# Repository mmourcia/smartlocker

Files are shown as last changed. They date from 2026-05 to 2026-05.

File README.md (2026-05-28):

# Smart Locker - Casiers connectés pilotés par Home Assistant

Une personne dépose un colis dans un casier libre, l'affecte à un destinataire via une interface mobile, et ce destinataire reçoit une notification puis récupère son colis en tapant son code personnel devant le meuble. Pas de clé, pas de badge obligatoire, pas d'attente.

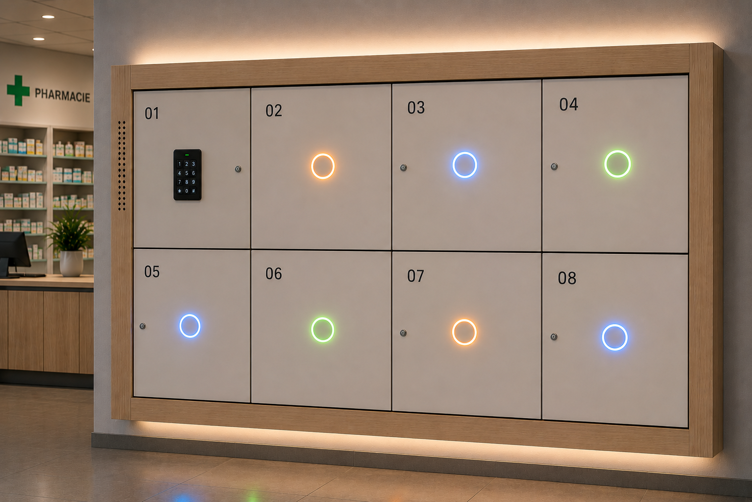
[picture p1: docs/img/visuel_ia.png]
Visuel IA


---

## Le principe

Le support est une étagère **IKEA Kallax 4x2** (8 casiers), chaque case étant équipée d'une porte, d'une serrure solénoïde et d'un anneau LED pour communiquer l'état au gestionnaire comme au destinataire.

Le cerveau du système est un **Raspberry Pi 4** sous Home Assistant OS. Deux cartes ESP32 lui sont connectées en WiFi : une carte 8 relais qui pilote les serrures et lit l'état des portes, et un digicode Wiegand 26 positionné devant le meuble.

Le système est conçu pour un usage intérieur en environnement de confiance. Pas de sécurité de niveau industriel : l'objectif est la praticité et la traçabilité légère.

---

## Ce que voit l'utilisateur

Un casier passe par quatre états, lisibles d'un coup d'oeil sur l'anneau LED :

| Couleur | État |
|---|---|
| 🟢 Vert fixe | Casier libre |
| 🔵 Bleu fixe | Occupé, destinataire notifié |
| 🟢 Vert clignotant (un seul, autres éteints) | Code correct, ce casier va s'ouvrir |
| 🟠 Orange clignotant | Porte ouverte depuis trop longtemps |
| 🔴 Rouge clignotant (tous, 3s) | Code incorrect |
| 🔴 Rouge fixe | Casier hors service |

---

## Documentation technique

Tout ce qu'il faut pour construire et configurer le système :

- [Serrure solénoïde](docs/hardware/serrure.md) - pilotage relais et retour via reed switch
- [Alimentation](docs/hardware/alimentation.md) - architecture 230V / 12V 20A
- [Contrôleur LED WLED Gledopto](docs/hardware/wled-gledopto.md) - 4 voies pour 8 casiers
- [Fraisage logements LED](docs/hardware/fraisage.md) - gabarit 3D et défonceuse
- [ESPHome - Carte relais](docs/esphome/carte-relais.md) - config complète LC-Relay-ESP32-8R-D5
- [ESPHome - Digicode Wiegand 26](docs/esphome/digicode-wiegand.md) - saisie code PIN
- [Home Assistant - Intégrations](docs/home-assistant/integrations.md) - entités, helpers, automatisations
- [Backend Python](docs/backend/README.md) - logique métier (à venir)

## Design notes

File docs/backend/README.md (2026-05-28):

# Backend Python - Logique métier

> **Statut : à venir.** Cette section sera complétée quand le backend sera développé.

## Motivation

Les automatisations Home Assistant YAML atteignent leurs limites pour :
- La vérification des codes PIN (logique conditionnelle complexe sur N casiers × M utilisateurs)
- La gestion des états métier avec transitions validées
- L'historisation des événements (qui a ouvert quoi, quand)
- Une future API REST pour piloter le système depuis une app mobile

## Architecture envisagée

```
Home Assistant
    │  webhooks / MQTT / WS
    ▼
Backend Python (FastAPI ou Flask)
    ├── Gestion des casiers (états, attribution, historique)
    ├── Gestion des utilisateurs (PIN hashé, préférences)
    ├── Vérification PIN (bcrypt)
    └── Notifications (email, push)
    │
    ▼
SQLite (ou PostgreSQL si volumétrie)
```

## Interactions avec Home Assistant

Le backend peut interagir avec HA de plusieurs façons :

| Mécanisme | Sens | Usage |
|---|---|---|
| Webhook HA | HA → Backend | Transmettre le code saisi par le digicode |
| REST API HA | Backend → HA | Déclencher ouverture (`button.press`), changer LED |
| MQTT | Bidirectionnel | Bus événements temps réel |
| Long-lived token HA | Auth | Token d'accès pour l'API HA |

## Structure de projet envisagée

```
backend/
├── app/
│   ├── main.py          # Point d'entrée FastAPI
│   ├── models.py        # Modèles SQLAlchemy (Casier, Utilisateur, Événement)
│   ├── api/
│   │   ├── lockers.py   # Endpoints casiers
│   │   └── users.py     # Endpoints utilisateurs
│   ├── services/
│   │   ├── pin.py       # Vérification PIN, hash bcrypt
│   │   ├── ha_client.py # Client API Home Assistant
│   │   └── notify.py    # Notifications email/push
│   └── config.py        # Variables d'environnement
├── tests/
├── requirements.txt
└── .env.example
```

## Sécurité

- Les PIN seront stockés hashés avec **bcrypt** (pas en clair comme dans les helpers HA V1)
- Le backend tourne en local sur le Raspberry Pi, pas exposé sur internet
- Authentification par token entre HA et le backend

## Déploiement sur le Raspberry Pi

Le backend tournera probablement comme un **add-on Home Assistant** ou un service systemd,
en parallèle de Home Assistant OS.

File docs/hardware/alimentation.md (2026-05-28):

# Alimentation

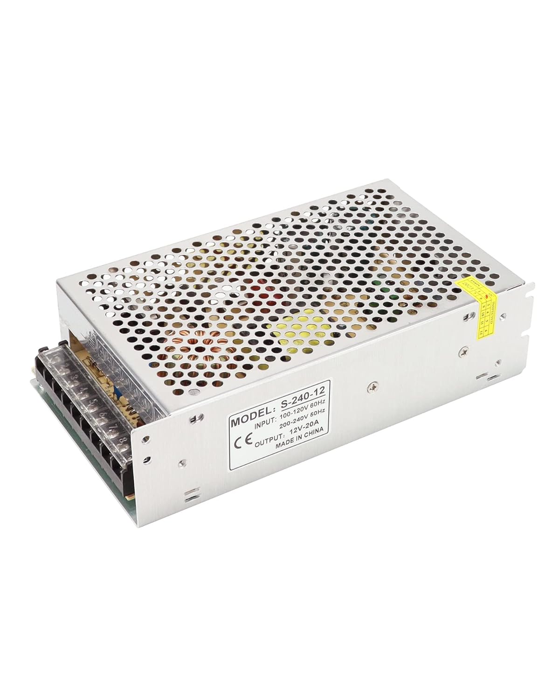
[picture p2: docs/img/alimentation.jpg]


## Architecture

| Source | Consommateur |
|---|---|
| Transformateur 12V / 20A | Carte ESP32, serrures x8, anneaux LED x8 |
| Alimentation USB-C officielle Raspberry Pi | Raspberry Pi 4 |

## Pourquoi 20A sur le 12V ?

| Consommateur | Courant estimé |
|---|---|
| Solénoïdes x8 (inrush simultané max) | 8 x 1 A = 8 A |
| Carte LC-Relay-ESP32-8R-D5 | ~0,5 A |
| Anneaux NeoPixel WS2812B x8 (plein blanc) | 8 x 0,72 A = ~5,8 A |
| **Total crête théorique** | **~14 A** |

En pratique les solénoïdes fonctionnent en impulsionnel (400 ms) et ne sont jamais tous actifs simultanément. Les LED ne sont jamais toutes à plein blanc. Un transformateur 12V / 20A offre une marge confortable.

## Distribution 12V

Le transformateur dispose directement de plusieurs paires de bornes V+/V- en sortie. Chaque consommateur (serrures, anneaux LED, carte ESP32) est raccordé directement sur ces bornes avec du câble 2x0,5 mm².

## Bouton d'urgence

Le bouton connecte directement le +12V sur toutes les serrures, sans passer par les relais ni l'ESP32. Il fonctionne même en cas de panne logicielle. À placer dans un endroit à accès restreint.

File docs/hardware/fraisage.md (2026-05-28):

# Fraisage - Logements anneaux LED dans le Kallax

## Principe

Chaque casier du Kallax reçoit un anneau NeoPixel WS2812B 12 LEDs. Pour l'intégrer proprement dans
la paroi ou la porte, un logement circulaire est fraisé à la défonceuse avec une bague de copiage
et un gabarit imprimé en 3D.

## Matériel

| Outil | Référence |
|---|---|
| Défonceuse | PARKSIDE POF 1200 ou Einhell TE-RO 1255 E (compatibles) |
| Bague de copiage | Imprimée en 3D - voir `3d/` |
| Gabarit anneau LED | `3d/gabarit_anneau_led.3mf` |
| Fraise | Fraise droite Ø selon logement anneau |

## Fichiers 3D

Les fichiers sont dans le répertoire [`3d/`](../../3d/) :

| Fichier | Description |
|---|---|
| `gabarit_anneau_led.3mf` | Gabarit de guidage pour fraiser le logement de l'anneau LED |
| `Guide_Bushing_30mm_Einhell_Router_TE-RO_1255_E.3mf` | Bague de copiage 30 mm pour Einhell TE-RO 1255 E |

Bague de copiage PARKSIDE POF 1200 : [modèle Printables](https://www.printables.com/model/556732-copy-ring-for-parkside-pof-1200-d3-router/files)

## Procédure

1. Imprimer le gabarit `gabarit_anneau_led.3mf` et la bague de copiage adaptée à la défonceuse.
2. Fixer le gabarit sur la paroi du casier (serre-joints ou double face fort).
3. Monter la bague de copiage sur la semelle de la défonceuse.
4. Fraiser en plusieurs passes (profondeur max 3–4 mm par passe dans le panneau Kallax).
5. Nettoyer les copeaux, tester le fit de l'anneau avant collage.

## Notes

- Les panneaux Kallax sont en **aggloméré de particules** avec un placage mélaminé : la fraise
  attaque facilement mais l'arrachement est possible en bord si la vitesse d'avance est trop élevée.
  Préférer une vitesse de rotation élevée et une avance lente.
- Pré-percer un trou de dégagement pour le câble de l'anneau avant de fraiser le logement.

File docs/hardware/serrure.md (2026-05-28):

# Serrure solénoïde

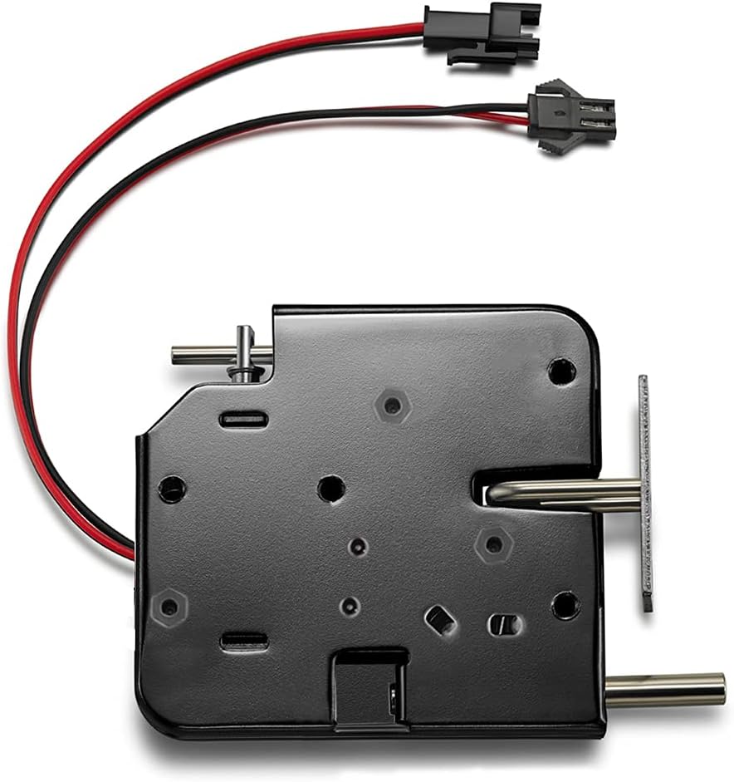
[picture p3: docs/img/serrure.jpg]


Référence : **Amazon B07KWMH16C** - solénoïde de porte 12V DC, type fail-secure.

> **Attention** : ne jamais maintenir la serrure alimentée en continu plus de 5 secondes. Le solénoïde chauffe très vite et grille. Une impulsion courte (400 ms) suffit, le mécanisme mécanique maintient l'ouverture jusqu'à ce que la porte soit refermée.

---

## Principe de fonctionnement

La serrure est de type **fail-secure** : sans courant, le verrou est sorti et la porte est verrouillée. C'est le comportement souhaité en cas de coupure de courant ou de panne du système.

| Alimentation | Verrou | Porte |
|---|---|---|
| 0V (repos) | Sorti | Verrouillée |
| 12V (impulsion) | Rentré | Déverrouillée |

La serrure est également équipée d'un **axe métallique sur ressort** qui pousse physiquement la porte dès que le verrou rentre. Pas besoin de tirer : la porte s'entrouvre d'elle-même à l'ouverture.

---

## Pilotage via relais

Chaque serrure est commandée par un relais de la carte LC-Relay-ESP32-8R-D5.

Le relais se comporte comme un interrupteur commandé par l'ESP32. Au repos, ses contacts sont ouverts et la serrure ne reçoit pas de courant. Quand l'ESP32 active le relais, les contacts se ferment et le +12V alimente le solénoïde pendant la durée de l'impulsion.

Le relais dispose de trois bornes :

- **COM** (common) - reliée au +12V de l'alimentation
- **NO** (normally open) - reliée au + du solénoïde, circuit ouvert au repos
- **NC** (normally closed) - non utilisée ici

Quand le relais s'active, COM et NO se connectent : le +12V passe dans le solénoïde, le verrou rentre, la porte s'ouvre.

---

## Retour d'état via reed switch

Un **reed switch MC-38** est fixé sur le châssis de chaque casier, en face d'un petit aimant solidaire de la porte.

Le reed switch est simplement deux fils. L'un est relié à un GPIO de l'ESP32 (pull-up activé), l'autre au GND. Quand la porte est fermée, l'aimant ferme le contact interne du reed switch et le GPIO lit LOW. Quand la porte s'ouvre, l'aimant s'éloigne, le contact s'ouvre et le GPIO lit HIGH.

| État de la porte | Contact reed switch | Valeur lue par l'ESP32 |
|---|---|---|
| Fermée | Fermé | LOW |
| Ouverte | Ouvert | HIGH |

ESPHome expose cet état comme un `binary_sensor` de classe `door`.

---

## Câblage (par casier)

### Serrure solénoïde

| Fil | Départ | Arrivée | Section |
|---|---|---|---|
| Alim + | +12V bornier | Borne COM du relais | 0,5 mm² |
| Alim + serrure | Borne NO du relais | Solénoïde (+) | 0,5 mm² |
| Alim - serrure | Solénoïde (-) | GND bornier | 0,5 mm² |

### Reed switch

| Fil | Départ | Arrivée | Section |
|---|---|---|---|
| Signal | GPIO_n de l'ESP32 (pull-up) | Borne A du reed switch | 0,22 mm² |
| Retour | Borne B du reed switch | GND | 0,22 mm² |

---

## Notes de montage

- Fixer la partie magnétique sur le battant de la porte, la partie contact sur le châssis fixe.
- Aligner soigneusement : le déclenchement doit être fiable jusqu'à 2 mm de jeu.
- Les GPIO 34, 35, 36 et 39 de l'ESP32 n'ont pas de pull-up interne - ajouter une résistance 10 kOhm externe vers le 3,3V pour ces entrées.

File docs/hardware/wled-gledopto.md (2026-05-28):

# Contrôleur LED WLED - Gledopto 4 voies

## Principe

Le contrôleur **Gledopto GL-C-007** (ou variante compatible WLED) est un contrôleur LED 4 voies
flashé avec le firmware [WLED](https://kno.wled.ge/). Il remplace les GPIO NeoPixel de l'ESP32 relais
pour la gestion des anneaux LED, et s'intègre nativement dans Home Assistant via l'intégration WLED.

## Mapping voies → casiers

Avec 4 voies pour 8 casiers, chaque voie pilote 2 anneaux en série ou en parallèle :

| Voie WLED | Casiers | Segment WLED |
|---|---|---|
| Voie 1 | Casier 1 + Casier 2 | Segment 0 (LEDs 0–23) |
| Voie 2 | Casier 3 + Casier 4 | Segment 1 (LEDs 0–23) |
| Voie 3 | Casier 5 + Casier 6 | Segment 2 (LEDs 0–23) |
| Voie 4 | Casier 7 + Casier 8 | Segment 3 (LEDs 0–23) |

> Chaque anneau WS2812B comprend 12 LEDs. 2 anneaux par voie = 24 LEDs par segment.
> Les 2 casiers d'une même voie partagent la couleur/animation - si on veut les différencier,
> il faut les câbler en série sur la même voie et définir des sous-segments dans WLED
> (LEDs 0–11 = casier A, LEDs 12–23 = casier B).

## Alimentation du contrôleur

Le Gledopto GL-C-007 accepte du **5V ou 12V** selon les broches utilisées. Les WS2812B fonctionnent en 5V.

```
Option A : 5V dédié
    Alim 5V/5A ──── Gledopto VIN/GND ──── Anneaux WS2812B

Option B : depuis le 12V (avec régulateur embarqué)
    12V alim principale ──── Gledopto VIN 12V ──── (régulateur interne) ──── WS2812B
```

Avec 8 anneaux × 12 LEDs × 60 mA (blanc plein) = **5,76 A en crête à 5V**.
Prévoir une alimentation 5V/6A dédiée ou s'assurer que le 12V/20A supporte la conversion.

## Intégration WLED

WLED expose une API HTTP/WebSocket et se découvre automatiquement via mDNS. Home Assistant
l'intègre nativement sans configuration manuelle :

1. WLED se connecte au WiFi (même réseau que le Raspberry Pi)
2. Home Assistant découvre automatiquement l'appareil (`Paramètres > Appareils et services`)
3. Les entités générées incluent :
   - `light.wled_smartlocker` - contrôle global
   - Segments individuels si configurés dans WLED

## Configuration WLED recommandée

Dans l'interface WLED (`http://<ip-wled>/`), créer 4 segments nommés :

| Segment | Nom | LEDs début | LEDs fin |
|---|---|---|---|
| 0 | casiers_1_2 | 0 | 23 |
| 1 | casiers_3_4 | 0 | 23 |
| 2 | casiers_5_6 | 0 | 23 |
| 3 | casiers_7_8 | 0 | 23 |

> Si les voies sont câblées indépendamment (GND/DATA séparés), chaque voie = un segment distinct
> dans WLED avec ses propres LEDs 0 à 23.

## Presets WLED pour les états casier

Créer des presets dans WLED pour chaque état :

| Preset | Couleur | Animation | État casier |
|---|---|---|---|
| 1 | Vert `#00FF00` | Fixe | Libre |
| 2 | Bleu `#0000FF` | Fixe | Occupé, destinataire notifié |
| 3 | Vert `#00FF00` | Clignotant 1 Hz | Code correct, casier sur le point de s'ouvrir |
| 4 | Éteint | - | Autres casiers pendant l'ouverture (focus sur le casier 3) |
| 5 | Orange `#FF8C00` | Clignotant rapide 4 Hz | Porte ouverte depuis trop longtemps |
| 6 | Rouge `#FF0000` | Clignotant 2 Hz | Code incorrect (tous les casiers, 3s) |
| 7 | Rouge `#FF0000` | Fixe | Casier hors service |

Ces presets sont appelables depuis Home Assistant via le service `wled.preset` ou via l'API REST WLED.

## Contrôle depuis Home Assistant

```yaml
# Exemple : allumer le segment casiers_1_2 en vert (casier libre)
service: light.turn_on
target:
  entity_id: light.wled_casiers_1_2
data:
  rgb_color: [0, 255, 0]
  brightness: 128
```

Ou via preset WLED :

```yaml
service: rest_command.wled_preset
data:
  ip: "192.168.1.x"
  preset: 1
  seg: 0
```

## Références

- [Firmware WLED](https://kno.wled.ge/)
- [Gledopto GL-C-007 sur WLED](https://kno.wled.ge/basics/compatible-hardware/#gledopto)
- [Intégration WLED dans Home Assistant](https://www.home-assistant.io/integrations/wled/)

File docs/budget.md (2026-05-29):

# Budget

## Composants

| Composant | Qté | Prix unitaire | Total |
|---|---|---|---|
| Meuble IKEA Kallax 4x2 | 1 | 75,00 | 75,00 |
| Bloc porte Kallax | 8 | 17,50 | 140,00 |
| Mini PC Home Assistant | 1 | 200,00 | 200,00 |
| Alimentation 12V / 20A rail DIN | 1 | 55,00 | 55,00 |
| Rail DIN | 1 | 12,00 | 12,00 |
| Carte relais ESP32 (LC-Relay-ESP32-8R-D5) | 1 | 20,00 | 20,00 |
| Serrure solénoïde 12V + reed switch intégré | 8 | 15,00 | 120,00 |
| Ruban LED COB haute densité (3m, découpé x8) | 1 | 30,00 | 30,00 |
| Digicode Wiegand 26 | 1 | 25,00 | 25,00 |
| Cables, Wago | 1 | 50,00 | 50,00 |
| Convertisseur USB-UART TTL | 1 | 7,00 | 7,00 |
| Bouton d'urgence | 1 | 2,00 | 2,00 |
| Filament 3D (gabarits LED + bagues de copiage) | - | ~5,00 | 5,00 |
| **Total** | | | **741,00** |

## Non inclus

| Composant | Statut |
|---|---|
| Contrôleur WLED Gledopto 4 voies | A confirmer - non encore acheté |
| Coffret électrique | Optionnel |

## Prix par casier

741 euros pour 8 casiers soit **93 euros par casier**.

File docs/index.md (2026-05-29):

# Documentation Smart Locker

## Architecture

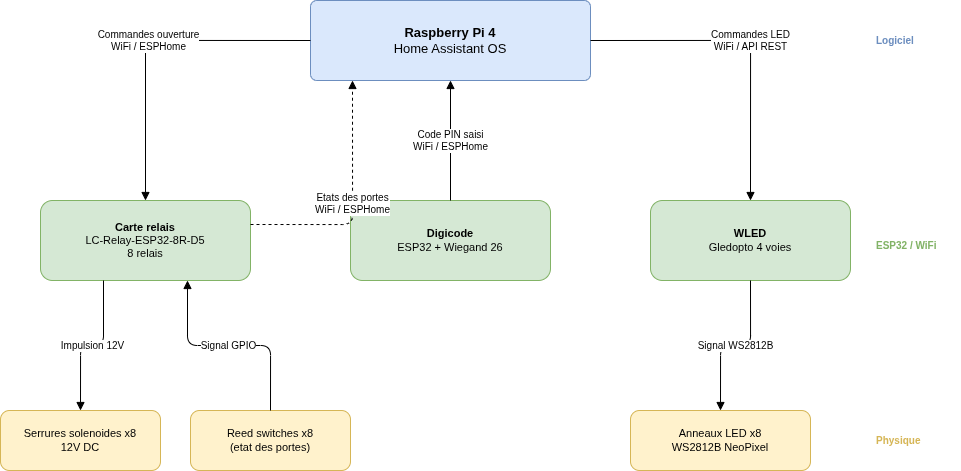
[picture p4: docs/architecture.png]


Le schéma source est disponible dans [architecture.drawio](architecture.drawio) (ouvrable sur [diagrams.net](https://app.diagrams.net)).

---

## Table des matières

### Matériel
- [Serrure solénoïde](hardware/serrure.md) - Pilotage via relais, retour d'état via reed switch
- [Alimentation](hardware/alimentation.md) - Architecture 230V → 12V/20A
- [Contrôleur LED WLED Gledopto](hardware/wled-gledopto.md) - Anneau LED par casier, 4 voies pour 8 casiers
- [Fraisage logements LED](hardware/fraisage.md) - Défonceuse, gabarit 3D, bague de copiage

### ESPHome
- [Carte relais LC-Relay-ESP32-8R-D5](esphome/carte-relais.md) - 8 relais, reed switches, NeoPixel
- [Digicode Wiegand 26](esphome/digicode-wiegand.md) - Saisie de code PIN, protocole Wiegand 26

### Home Assistant
- [Intégrations](home-assistant/integrations.md) - ESPHome, WLED, MQTT, helpers, entités

### Backend
- [Backend Python](backend/README.md) - Logique métier, gestion des casiers, API (à venir)

### Projet
- [Budget](budget.md) - Liste des composants et coûts

---

> Ce projet tourne sur un Raspberry Pi 4 sous Home Assistant OS.
> Support physique : IKEA Kallax 4×2 (8 casiers).
> Voir le [README principal](../README.md) pour la vue d'ensemble.

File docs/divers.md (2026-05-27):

# Notes et liens utiles

Page de collecte rapide. Le contenu structuré est dans les pages dédiées.

## Liens de référence

| Sujet | Lien |
|---|---|
| Pinout USB-UART carte 8 relais ESP32 | https://forum.hacf.fr/t/carte-8-relais-avec-esp32-branchement-usb-uart/48181 |
| Bague de copiage PARKSIDE POF 1200 | https://www.printables.com/model/556732-copy-ring-for-parkside-pof-1200-d3-router/files |

## Procédures en bref

- Flashage initial carte relais → voir [esphome/carte-relais.md](esphome/carte-relais.md#flashage-initial)
- Fraisage logements anneaux LED → voir [hardware/fraisage.md](hardware/fraisage.md)

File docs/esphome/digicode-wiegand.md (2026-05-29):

# ESPHome - Digicode Wiegand

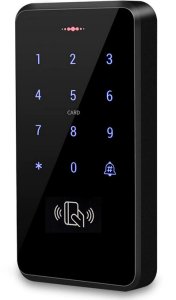
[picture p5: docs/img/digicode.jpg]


Référence : [composant wiegand ESPHome](https://esphome.io/components/wiegand/)

Le digicode se connecte à un ESP32 dédié via deux fils data (D0 et D1). L'ESP32 décode les touches
et les assemble en code PIN via le composant `key_collector`, puis transmet le code complet à
Home Assistant.

---

## Câblage

| Digicode | ESP32 |
|---|---|
| VCC | 12V |
| GND | GND |
| D0 | GPIO4 |
| D1 | GPIO5 |

> Les lignes D0/D1 fonctionnent en logique 5V. L'ESP32 tolère généralement ces niveaux en entrée,
> mais en cas de problème ajouter un diviseur de tension ou un level-shifter.

---

## Configuration ESPHome

Le composant `wiegand` capture chaque touche via `on_key`. Le composant `key_collector` les
assemble en séquence et déclenche l'envoi à Home Assistant quand l'utilisateur appuie sur `#`.
La touche `*` efface la saisie en cours.

```yaml
# smartlocker-digicode.yaml
substitutions:
  device_name: smartlocker-digicode
  friendly_name: "Smart Locker - Digicode"

esphome:
  name: ${device_name}
  friendly_name: ${friendly_name}

esp32:
  board: esp32dev
  framework:
    type: arduino

logger:
  level: INFO
  # Ne pas logger les codes PIN en production

api:
  encryption:
    key: !secret api_encryption_key
ota:
  password: !secret ota_password
wifi:
  ssid: !secret wifi_ssid
  password: !secret wifi_password

# Wiegand - capture touche par touche

wiegand:
  - id: keypad
    d0: GPIO4
    d1: GPIO5
    on_key:
      - key_collector.collect:
          id: pin_collector
          key: !lambda |
            if (x >= 0 && x <= 9) return ('0' + x);
            if (x == 10) return '*';
            if (x == 11) return '#';
            return 0;

# key_collector - assemble les touches en code PIN

key_collector:
  - id: pin_collector
    min_length: 4
    max_length: 8
    end_keys: "#"
    end_key_required: true
    back_keys: "*"
    timeout: 10s
    on_result:
      - text_sensor.template.publish:
          id: pin_code
          state: !lambda 'return x;'
      - homeassistant.event:
          event: esphome.keypad_code_entered
          data:
            code: !lambda 'return x;'
    on_timeout:
      - text_sensor.template.publish:
          id: pin_code
          state: ""

# Expose le dernier code saisi comme entite Home Assistant

text_sensor:
  - platform: template
    name: "Code digicode"
    id: pin_code
    icon: "mdi:dialpad"
```

### Touches speciales

| Valeur Wiegand | Touche physique | Role dans key_collector |
|---|---|---|
| 0-9 | Chiffres | Saisie du code |
| 10 | `*` | Efface la saisie en cours |
| 11 | `#` | Valide et envoie le code |

---

## Cote Home Assistant

Quand l'utilisateur valide avec `#`, l'evenement `esphome.keypad_code_entered` est fire avec le
code en data. Une automatisation HA se charge de verifier le code et d'ouvrir le bon casier.

```yaml
alias: "Digicode - verification code PIN"
trigger:
  - platform: event
    event_type: esphome.keypad_code_entered
action:
  - variables:
      code_saisi: "{{ trigger.event.data.code }}"
  # Verification et ouverture du casier - voir backend Python
```

> La logique de verification est plus propre dans le backend Python.
> Voir [backend/README.md](../backend/README.md).

---

## Notes

- Certains digicodes ont besoin d'une remise a zero usine pour passer en mode sortie Wiegand 26/34.
  Consulter la notice du modele si les touches ne sont pas recues par l'ESP32.
- Le `key_collector` attend `#` pour valider. Si le digicode envoie le PIN complet d'un coup
  via `on_tag` (comportement de certains modeles), utiliser directement `on_tag` et supprimer
  le `key_collector`.
- `text_sensor` publie le code en clair dans Home Assistant. Prevoir de l'effacer apres traitement.

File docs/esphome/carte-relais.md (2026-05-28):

# ESPHome - Carte relais LC-Relay-ESP32-8R-D5

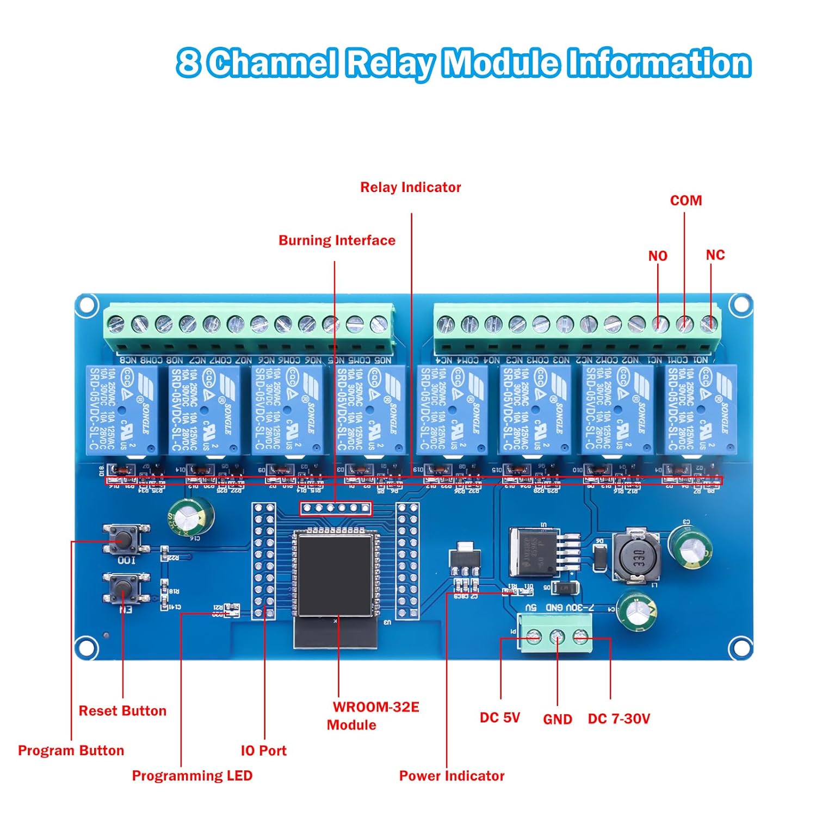
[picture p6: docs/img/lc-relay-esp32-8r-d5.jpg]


La **LC-Relay-ESP32-8R-D5** est une carte tout-en-un combinant :
- Un module **ESP32** (WiFi + Bluetooth)
- **8 relais** 10A/250VAC (utilisés ici en 12V DC)
- Alimentation directe en **12V** (régulateur embarqué 3.3V/5V pour l'ESP32)
- Connecteurs screw terminal pour chaque relais (COM/NO/NC)

## Brochage utilisé

| Fonction | GPIO ESP32 | Composant |
|---|---|---|
| Relais casier 1 | GPIO32 | Serrure solénoïde 1 |
| Relais casier 2 | GPIO33 | Serrure solénoïde 2 |
| Relais casier 3 | GPIO25 | Serrure solénoïde 3 |
| Relais casier 4 | GPIO26 | Serrure solénoïde 4 |
| Relais casier 5 | GPIO27 | Serrure solénoïde 5 |
| Relais casier 6 | GPIO14 | Serrure solénoïde 6 |
| Relais casier 7 | GPIO12 | Serrure solénoïde 7 |
| Relais casier 8 | GPIO13 | Serrure solénoïde 8 |
| Reed switch 1 | GPIO34 | État porte casier 1 |
| Reed switch 2 | GPIO35 | État porte casier 2 |
| Reed switch 3 | GPIO36 | État porte casier 3 |
| Reed switch 4 | GPIO39 | État porte casier 4 |
| Reed switch 5 | GPIO4 | État porte casier 5 |
| Reed switch 6 | GPIO16 | État porte casier 6 |
| Reed switch 7 | GPIO17 | État porte casier 7 |
| Reed switch 8 | GPIO5 | État porte casier 8 |

> **A vérifier** : les GPIO proposés pour les reed switches (GPIO4, 5, 16, 17, 34, 35, 36, 39) sont
> théoriquement libres sur un ESP32 standard, mais certains peuvent être utilisés par la carte pour
> d'autres fonctions selon la version du PCB. Vérifier le pinout exact sur le
> [forum HACF](https://forum.hacf.fr/t/carte-8-relais-avec-esp32-branchement-usb-uart/48181)
> avant de câbler.
>
> GPIO 34, 35, 36 et 39 sont en **entrée uniquement** sur l'ESP32 (pas de pull-up interne).
> Ajouter une résistance pull-up externe 10kΩ vers le 3,3V pour chacun de ces quatre GPIO.

## Configuration ESPHome

```yaml
# smartlocker-relais.yaml
substitutions:
  device_name: smartlocker-relais
  friendly_name: "Smart Locker - Relais"

esphome:
  name: ${device_name}
  friendly_name: ${friendly_name}

esp32:
  board: esp32dev
  framework:
    type: arduino

logger:
api:
  encryption:
    key: !secret api_encryption_key
ota:
  password: !secret ota_password
wifi:
  ssid: !secret wifi_ssid
  password: !secret wifi_password
  ap:
    ssid: "${device_name} Fallback"
    password: !secret fallback_password

# Relais

switch:
  - platform: gpio
    name: "Relais casier 1"
    id: relay_1
    pin: GPIO32
    restore_mode: ALWAYS_OFF

  - platform: gpio
    name: "Relais casier 2"
    id: relay_2
    pin: GPIO33
    restore_mode: ALWAYS_OFF

  - platform: gpio
    name: "Relais casier 3"
    id: relay_3
    pin: GPIO25
    restore_mode: ALWAYS_OFF

  - platform: gpio
    name: "Relais casier 4"
    id: relay_4
    pin: GPIO26
    restore_mode: ALWAYS_OFF

  - platform: gpio
    name: "Relais casier 5"
    id: relay_5
    pin: GPIO27
    restore_mode: ALWAYS_OFF

  - platform: gpio
    name: "Relais casier 6"
    id: relay_6
    pin: GPIO14
    restore_mode: ALWAYS_OFF

  - platform: gpio
    name: "Relais casier 7"
    id: relay_7
    pin: GPIO12
    restore_mode: ALWAYS_OFF

  - platform: gpio
    name: "Relais casier 8"
    id: relay_8
    pin: GPIO13
    restore_mode: ALWAYS_OFF

# Boutons virtuels - impulsion 400 ms
# Utilises par Home Assistant pour declencher l'ouverture d'un casier

button:
  - platform: template
    name: "Ouvrir casier 1"
    on_press:
      - switch.turn_on: relay_1
      - delay: 400ms
      - switch.turn_off: relay_1

  - platform: template
    name: "Ouvrir casier 2"
    on_press:
      - switch.turn_on: relay_2
      - delay: 400ms
      - switch.turn_off: relay_2

  - platform: template
    name: "Ouvrir casier 3"
    on_press:
      - switch.turn_on: relay_3
      - delay: 400ms
      - switch.turn_off: relay_3

  - platform: template
    name: "Ouvrir casier 4"
    on_press:
      - switch.turn_on: relay_4
      - delay: 400ms
      - switch.turn_off: relay_4

  - platform: template
    name: "Ouvrir casier 5"
    on_press:
      - switch.turn_on: relay_5
      - delay: 400ms
      - switch.turn_off: relay_5

  - platform: template
    name: "Ouvrir casier 6"
    on_press:
      - switch.turn_on: relay_6
      - delay: 400ms
      - switch.turn_off: relay_6

  - platform: template
    name: "Ouvrir casier 7"
    on_press:
      - switch.turn_on: relay_7
      - delay: 400ms
      - switch.turn_off: relay_7

  - platform: template
    name: "Ouvrir casier 8"
    on_press:
      - switch.turn_on: relay_8
      - delay: 400ms
      - switch.turn_off: relay_8

# Reed switches

binary_sensor:
  - platform: gpio
    name: "Porte casier 1"
    id: door_1
    pin:
      number: GPIO34
      mode: INPUT        # Pull-up externe 10kOhm requis
    device_class: door
    filters:
      - delayed_on: 50ms
      - delayed_off: 50ms

  - platform: gpio
    name: "Porte casier 2"
    id: door_2
    pin:
      number: GPIO35
      mode: INPUT        # Pull-up externe 10kOhm requis
    device_class: door
    filters:
      - delayed_on: 50ms
      - delayed_off: 50ms

  - platform: gpio
    name: "Porte casier 3"
    id: door_3
    pin:
      number: GPIO36
      mode: INPUT        # Pull-up externe 10kOhm requis
    device_class: door
    filters:
      - delayed_on: 50ms
      - delayed_off: 50ms

  - platform: gpio
    name: "Porte casier 4"
    id: door_4
    pin:
      number: GPIO39
      mode: INPUT        # Pull-up externe 10kOhm requis
    device_class: door
    filters:
      - delayed_on: 50ms
      - delayed_off: 50ms

  - platform: gpio
    name: "Porte casier 5"
    id: door_5
    pin:
      number: GPIO4
      mode: INPUT_PULLUP
    device_class: door
    filters:
      - delayed_on: 50ms
      - delayed_off: 50ms

  - platform: gpio
    name: "Porte casier 6"
    id: door_6
    pin:
      number: GPIO16
      mode: INPUT_PULLUP
    device_class: door
    filters:
      - delayed_on: 50ms
      - delayed_off: 50ms

  - platform: gpio
    name: "Porte casier 7"
    id: door_7
    pin:
      number: GPIO17
      mode: INPUT_PULLUP
    device_class: door
    filters:
      - delayed_on: 50ms
      - delayed_off: 50ms

  - platform: gpio
    name: "Porte casier 8"
    id: door_8
    pin:
      number: GPIO5
      mode: INPUT_PULLUP
    device_class: door
    filters:
      - delayed_on: 50ms
      - delayed_off: 50ms
```

## Points d'attention

- **restore_mode: ALWAYS_OFF** : garantit que les relais sont ouverts au redémarrage.
- L'ESP32 de cette carte peut avoir les niveaux de GPIO relais inversés (actif LOW) selon la version du PCB. Si les relais fonctionnent à l'envers, ajouter `inverted: true` sur les pins concernées.

## Flashage initial

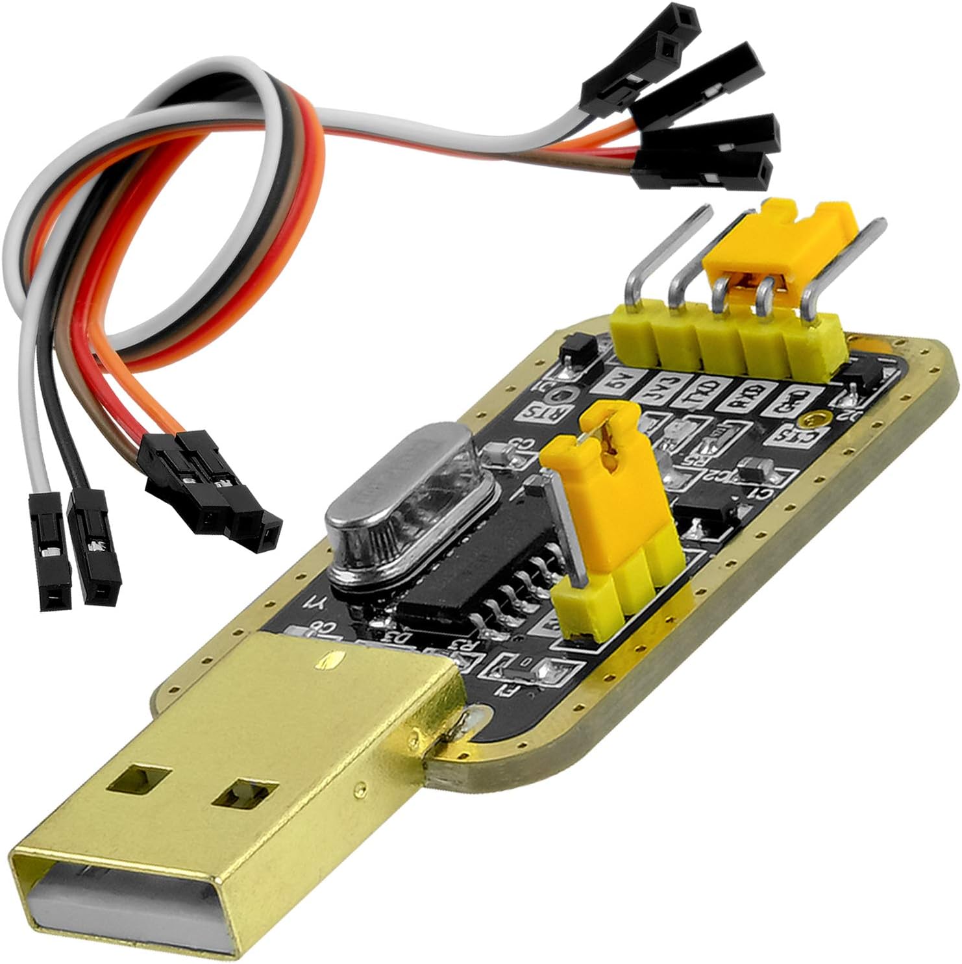
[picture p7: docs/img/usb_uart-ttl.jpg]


La carte ne dispose pas d'un port USB natif. Le premier flash passe par un adaptateur **USB-UART TTL** externe.

Pinout de la carte : [forum HACF](https://forum.hacf.fr/t/carte-8-relais-avec-esp32-branchement-usb-uart/48181)

### Câblage USB-UART vers carte

| USB-UART | Carte LC-Relay |
|---|---|
| TX | RX de la carte |
| RX | TX de la carte |
| GND | GND |
| 5V | VCC de la carte |

Le 5V fourni par l'adaptateur USB-UART suffit à alimenter l'ESP32 pendant le flash.

### Passage en mode flash

Mettre un cavalier entre **GND et GPIO0** avant de brancher l'USB-UART, pour forcer l'ESP32 en mode bootloader. Retirer le cavalier après le flash.

### Commande

```bash
esphome compile smartlocker-relais.yaml

esptool --chip esp32 \
        --port /dev/ttyUSB0 \
        --baud 460800 \
        write_flash -z 0x0 \
        ~/Telechargenents/smartlocker-relais.factory.bin
```

Identifier le bon port avec `ls /dev/tty*` avant et après branchement de l'adaptateur.

Les mises à jour suivantes se font en OTA depuis l'interface ESPHome de Home Assistant.

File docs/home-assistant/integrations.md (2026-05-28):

# Home Assistant - Intégrations

## Vue d'ensemble

| Intégration | Protocole | Rôle |
|---|---|---|
| **ESPHome** (relais) | WiFi / API native | Commande serrures, lecture reed switches |
| **ESPHome** (digicode) | WiFi / API native | Réception codes PIN saisis |
| **WLED** | WiFi / API REST + mDNS | Pilotage anneaux LED par casier |
| **MQTT** | TCP/IP | Optionnel - bus événements entre composants |
| **notify.smtp** | SMTP | Email de notification au destinataire |

## ESPHome - Carte relais

L'intégration ESPHome s'ajoute automatiquement dès que l'ESP32 est flashé et joignable sur le réseau.

Entités exposées par la carte relais :

| Entité | Type | Description |
|---|---|---|
| `button.ouvrir_casier_N` | Button | Déclenche l'impulsion relais |
| `binary_sensor.porte_casier_N` | Binary sensor | État physique de la porte (reed switch) |

## ESPHome - Digicode

Entités / événements exposés :

| Entité / Événement | Type | Description |
|---|---|---|
| `text_sensor.code_digicode` | Text sensor | Dernier code saisi (effacé après traitement) |
| `esphome.keypad_code_entered` | Event | Code saisi, déclenche la vérification dans HA |

## WLED - Gledopto

Après découverte automatique, Home Assistant génère :

| Entité | Type | Description |
|---|---|---|
| `light.wled_smartlocker` | Light | Contrôle global |
| `light.wled_casiers_1_2` | Light | Segment voie 1 |
| `light.wled_casiers_3_4` | Light | Segment voie 2 |
| `light.wled_casiers_5_6` | Light | Segment voie 3 |
| `light.wled_casiers_7_8` | Light | Segment voie 4 |

## Helpers (input_*)

Les états métier des casiers et les données utilisateurs sont stockés dans des helpers HA :

### État des casiers

```yaml
# configuration.yaml ou via UI : Paramètres > Appareils > Helpers
input_select:
  casier_1_etat:
    name: "État casier 1"
    options: [libre, occupé, en_attente, ouvert]
    initial: libre
  # ... répéter pour casiers 2 à 8
```

### Destinataires et PIN

```yaml
input_text:
  casier_1_destinataire:
    name: "Destinataire casier 1"
    max: 50

input_text:
  user_alice_pin:
    name: "PIN Alice"
    max: 8
    mode: password   # masqué dans l'UI
  user_bob_pin:
    name: "PIN Bob"
    max: 8
    mode: password
```

> Les PIN en mode `password` sont masqués dans Lovelace mais stockés en clair dans le fichier
> d'état HA. Pour la V1 (usage interne réseau local), c'est acceptable. Une V2 pourrait
> déléguer la vérification au backend Python avec des hash bcrypt.

## Automatisations principales

| Automatisation | Déclencheur | Action |
|---|---|---|
| Vérification code PIN | `esphome.keypad_code_entered` | Identifier casier/user, ouvrir si OK, LED feedback |
| Détection porte ouverte | `binary_sensor.porte_casier_N` → ON | Passer casier en état `ouvert`, LED blanc clignotant |
| Détection porte refermée | `binary_sensor.porte_casier_N` → OFF + état `ouvert` | Passer casier en état `libre`, LED vert |
| Notification dépôt | Changement état `libre` → `occupé` | Email au destinataire désigné |
| LED par état | Changement `input_select.casier_N_etat` | Appel service `light.turn_on` sur segment WLED |

## Mise à jour du README principal

Penser à mettre à jour le tableau "Couche logicielle" dans [README.md](../../README.md)
quand de nouvelles intégrations sont ajoutées (WLED, backend Python...).

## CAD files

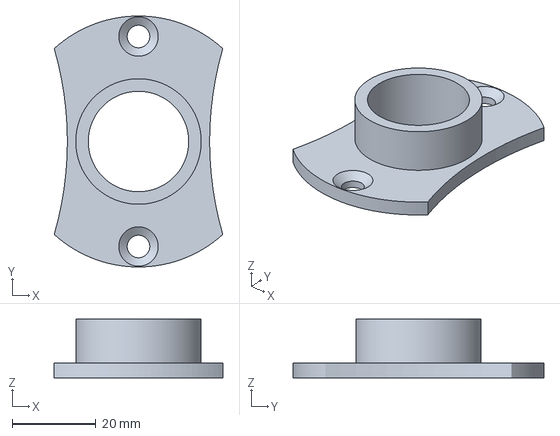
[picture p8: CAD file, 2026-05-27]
3d/Guide_Bushing_30mm_Einhell_Router_TE-RO_1255_E.3mf
40.3 x 60.0 x 14.0 mm

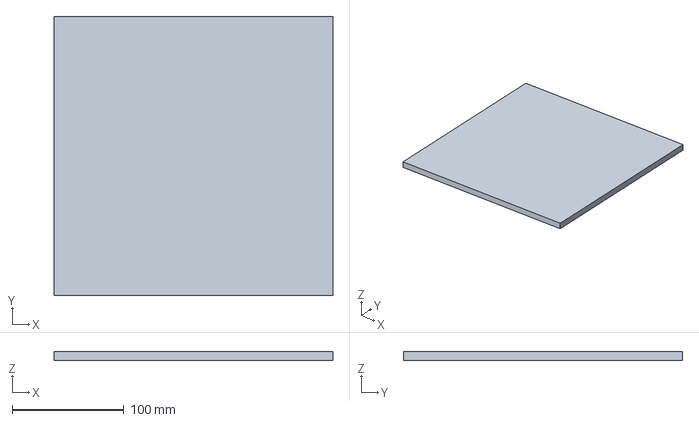
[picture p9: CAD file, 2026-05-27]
3d/gabarit_anneau_led.3mf
250.0 x 250.0 x 8.00 mm

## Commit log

2026-05-27 Toute la doc
    [Guide_Bushing_30mm_Einhell_Router_TE-RO_1255_E.3mf, gabarit_anneau_led.3mf]
2026-05-28 grosse maj de doc
2026-06-02 Gestion des notifs sms mail etc + maj doc
2026-10-12 LED WLED pilotées par smart_locker, alignement doc et ESPHome sur le réel
    Mise à jour du dépôt (objectif 1)
    - Versionne les YAML ESPHome réels (esphome/), secrets externalisés + secrets.yaml.example
    - Case 3 = compartiment technique : exclue du composant (LOCKER_IDS), des services et des cartes
    - Doc carte relais : nouveau brochage reed (pull-up interne), flash via esphome run
    - Doc digicode : PIN 6 chiffres validé automatiquement, plus de touche #
    - README, index, backend, serrure, alimentation alignés ; suppression d'un PDF hors sujet
    Éclairage et correctifs (objectif 2)
    - leds.py : pilotage WLED via l'API JSON (une requête pour les 8 segments), code couleur
    des presets 120-1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
2026-10-12 Badges, templates de messages, casiers persistants, récupération confirmée par la porte
    Casiers
    - État, PIN et assignations persistés dans .storage/smart_locker_lockers à chaque
    changement : plus rien n'est perdu au redémarrage de HA ou sur coupure de courant
    - Destinataires référencés par id : un renommage ne casse plus les assignations
    (services assign/unassign acceptent recipient_id, ou user pour compatibilité)
    - Récupération confirmée par le reed switch (porte ouverte < 30 s après le bon PIN ou
    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
2026-10-12 Budget réel d'après les commandes Amazon
    Synthèse par poste, détail des 29 lignes de commande (769,04 € TTC), éléments hors
    Amazon estimés, coût par casier sur 7 casiers, écarts relevés avec la doc matérielle.
2026-10-12 Budget : coût du système vs achats non utilisés, convertisseur 5V documenté
    - Coût du système installé (Mean Well, une seule carte relais) : ~980 €, ~140 € par casier
    - Achats non utilisés isolés : 2 cartes relais HS, alimentation QWORK remplacée
    - Convertisseur 12V -> 5V : alimentation de l'ESP32 du digicode (alimentation, digicode)
2026-10-12 Budget : uniquement les dépenses réelles du locker
    Retrait des achats non utilisés (synthèse et détail des commandes).
2026-10-12 Fiche technique imprimable (câblage + dépannage)
    Feuille A4 recto-verso à laisser dans le compartiment technique : correspondance
    casiers / relais / reeds / segments WLED, connecteur des reeds, serrures, digicode,
    alimentation et bouton d'urgence, réseau ; code LED, symptômes et vérifications,
    gestes utiles, interdits, QR code vers le dépôt. Source HTML + PDF généré par Chrome.
2026-10-12 Ouverture de secours manuelle à la place du bouton d'urgence
    Pas de bouton d'urgence ni de diodes : procédure fil volant COM-NO (12V OK) ou
    batterie sur NO (12V HS), jamais sur COM. Fiche : section réseau retirée.
    Budget : diodes et bouton retirés (~971 €, ~139 € par casier).
2026-10-12 Fiche : flash initial pas à pas (cavalier G0-GND), section symptômes retirée
    Les infos utiles des symptômes (reed bloqué, clavier hors Wiegand 26) passent
    dans les gestes utiles.
2026-10-12 README : retrait de la roadmap (tout est implémenté)
2026-10-12 Casier hors service : service set_out_of_service et bouton dans la carte Casier
    Contenu conservé, PIN et badge inopérants, assignation et notification refusées,
    Libérer garde le casier hors service, état recalculé à la remise en service. v0.6.0.
2026-10-12 Suppression du fraisage des anneaux LED (abandonné)
    Page fraisage, gabarit et bague de copiage 3D retirés ; filament retiré du budget.
2026-10-12 Schéma d'architecture à jour (SVG)
    Mini PC, 7 casiers, rubans COB, badges, alimentation 12V / 5V ; remplace
    l'ancien PNG/drawio (Raspberry Pi, 8 casiers, anneaux NeoPixel).
2026-10-12 Carte Casiers : vue d'ensemble mobile de tous les casiers
    Nouvelle carte smart-locker-lockers-card : grille compacte responsive (2 colonnes
    sur téléphone), couleurs alignées sur les LED, porte ouverte en orange, résumé en
    en-tête ; détail au toucher avec l'action utile selon l'état. Ancienne carte :
    boutons qui passent à la ligne au lieu de déborder. v0.7.0.
2026-10-12 Carte Casiers : grille calquée sur le meuble
    Impairs à gauche, pairs à droite, case technique conservée à sa place (grisée,
    sans action) ; options cases / columns / technical.
2026-10-12 Carte Destinataires : liste de fiches lisible sur mobile
    Le tableau à 7 colonnes est remplacé par une fiche par destinataire (nom, contact,
    services, badge, actions), triée par nom ; formulaire en grille adaptative.
2026-10-13 Carte Matériel : choix de la carte relais, du digicode et du WLED
    Les entités de la carte relais ne dépendent plus d'entity_id fixes : elles sont
    retrouvées sur l'appareil ESPHome choisi (ou détecté automatiquement) d'après leur
    nom d'origine (« Ouvrir casier N », « Porte casier N »), donc insensibles aux
    suffixes _2 et aux renommages ; anciens entity_id en dernier recours. Liaison
    recalculée à chaque changement d'appareil ou d'entité. Digicode : si choisi, seuls
    ses événements sont écoutés. Nouvelle carte smart-locker-hardware-card avec l'état
    de la liaison casier par casier ; le choix du WLED y est déplacé. v0.8.0.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
2026-10-13 Envoi intégré des notifications : email (SMTP) et SMS (SMSFactor)
    Les services notify YAML (platform smtp / rest) sont en cours d'abandon dans HA et
    les entités notify n'acceptent pas de destinataire : le composant envoie lui-même,
    aux coordonnées de la carte Destinataires.
    - notifier.py : SMTP (STARTTLS / SSL, texte + HTML, nom d'expéditeur) via la
    bibliothèque standard, SMSFactor via son API HTTP (numéros convertis au format
    international), état du dernier envoi par canal
    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
2026-10-13 secrets.yaml.example : valeurs d'exemple sans ambiguïté
    L'ancien marqueur "base64==" était recopié comme préfixe de la clé API. Précise
    aussi qu'en migration il faut reprendre la clé API et le mot de passe OTA actuels.
    (cherry picked from commit 8c38d2097c2d64260a3437092058c6c2d09ef634)
2026-10-13 Destinataires mis à jour en direct dans toutes les cartes
    Nouvelle souscription smart_locker/recipients/subscribe (signal émis à chaque
    enregistrement) : un destinataire ajouté, modifié ou supprimé apparaît aussitôt
    dans les cartes Casiers, Casier et Destinataires de tous les appareils, sans F5.
    Désabonnement quand la carte quitte l'écran. v0.9.1.
2026-10-15 Dépôt compatible HACS (dépôt personnalisé)
    - Intégration déplacée de homeassistant/custom_components/ vers custom_components/
    à la racine (exigence HACS), historique conservé
    - hacs.json ; manifest complété (documentation, issue_tracker, codeowners)
    - Doc : installation par HACS recommandée, procédure de publication d'une version ;
    version retirée de la fiche technique (elle ne serait jamais à jour)
    - v0.10.0
2026-10-15 Icône de l'intégration (dossier brand/, HA 2026.3+)
    Meuble Kallax 2x4 avec un casier « colis prêt » en vert et la case technique ;
    PNG 256 et 512 px à fond transparent, source SVG dans docs/img/icone.svg. v0.10.1.
